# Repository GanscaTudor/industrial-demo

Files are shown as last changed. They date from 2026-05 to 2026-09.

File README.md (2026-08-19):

# Industrial Demo — 10BASE-T1L Control Network

Industrial control network demo using Analog Devices 10BASE-T1L Single Pair Ethernet. A Raspberry Pi running Kuiper Linux 2 acts as the central controller, communicating with multiple ADI evaluation boards over T1L to drive servomotors, control an LED, read temperatures, and drive a DC fan — all managed from a single Python GUI.

## Mechanical Design

<table>
  <tr>
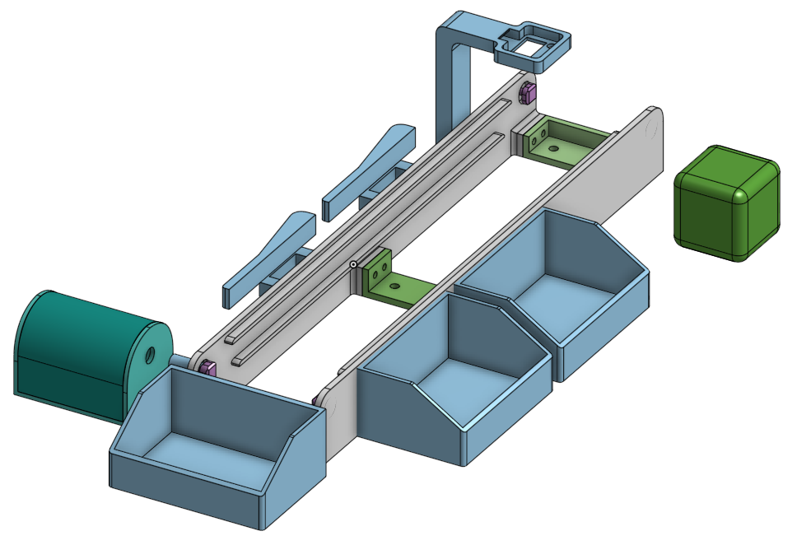
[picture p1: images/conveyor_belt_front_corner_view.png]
Conveyor Belt — Front Corner View
    <td></td>
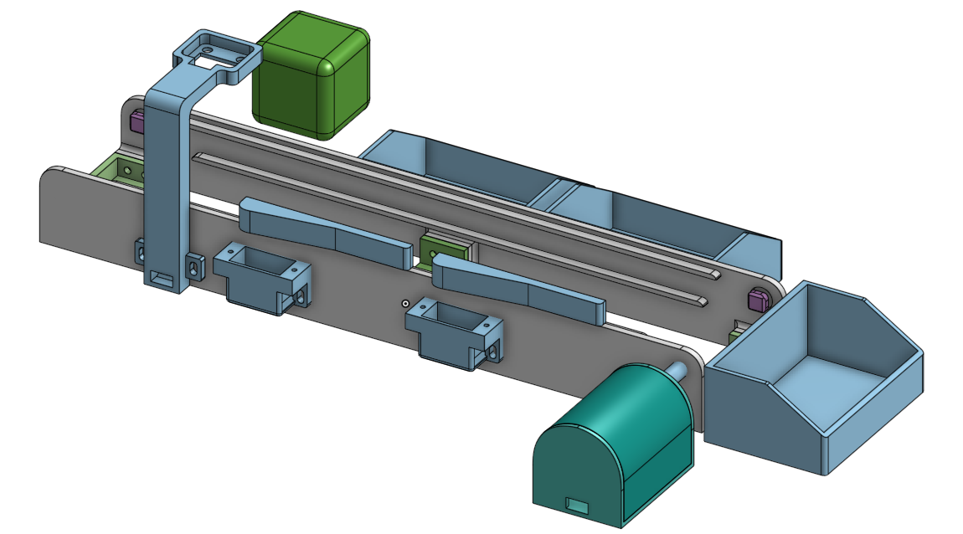
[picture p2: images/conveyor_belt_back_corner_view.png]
Conveyor Belt — Back Corner View
    <td></td>
  </tr>
</table>

### Bill of Materials (BOM)

| Part | Description | Part No. | Qty | Vendor | Filament (g) |
| --- | --- | --- | ----- | --- | --- |
| Roller bearing | Deep groove ball bearing, 3×10×4 mm, double-shielded | SKF 623-2Z | 4 | [TME](https://www.tme.eu/en/details/skf623-2z/roller-bearings/skf/623-2z-skf/) | — |
| DC gearmotor | 195:1 metal gearmotor, 20D×44L mm, 6V | Pololu 3707 | 1 | [TME](https://www.tme.eu/en/details/pololu-3707/dc-motors/pololu/195-1-metal-gearmotor-20dx44l-mm-6v-cb/) | — |
| Color sensor | Analog color sensor (colorimeter) | DFRobot SEN0212 | 1 | [TME](https://www.tme.eu/ro/details/df-sen0212/senzori-de-mediu/dfrobot/sen0212/) | — |
| Accelerometer eval board | Low noise, low drift 3-axis accelerometer, PMOD board | EVAL-ADXL355-PMDZ | 1 | [Analog Devices](https://www.analog.com/en/resources/evaluation-hardware-and-software/evaluation-boards-kits/eval-adxl355-pmdz.html) | — |
| Threaded insert | Brass threaded insert for plastic parts (used with the 14 M3 screws below) | Tappex KVT-M3 (KVT-117M3) | 14 | [TME](https://www.tme.eu/ro/details/kvt-117m3/inserturi-filetate/tappex/117m3/) | — |
| M3 screw | For the threaded inserts above | Generic M3 | 10 | — | — |
| M3 screw | For servo / color sensor / ADXL355 holder mounting (paired with nut below) | Generic M3 | 14 | — | — |
| M3 nut | Paired with the 14 holder-mounting screws above | Generic M3 | 14 | — | — |
| 3D-printed parts | Chassis, holders, connectors — see[`CAD/parts`](CAD/parts/) and [`CAD/printable`](CAD/printable/) | Custom | 1 set | In-house (3D print) | ~700 (PLA or PETG) |

### CAD Files

CAD files are in [`CAD/`](CAD/):

- `CAD/assembly/` — full assembly (STEP)
- `CAD/parts/` — individual custom parts (STEP), named by part number
- `CAD/printable/` — 3D-printable parts (3MF)

### Build Steps

1. 3D-print all parts.
2. Heat-set the threaded inserts into the `side` part using a soldering iron.
3. Assemble the side panels using the connectors and screws into the inserts.
4. Drill holes in the side panel at the locations where the servo holder and color sensor holder will be mounted.
5. Mount the hardware into its holders (servo into its holder, DC motor into its case, color sensor into its housing, etc.).
6. Mount the housings with the hardware onto the side panel at the drilled holes, using M3 screws and nuts.
7. Insert the connectors into the bearing bores and each bearing into its position. Note that one bearing uses the elongated connector, which mates with the longer connector going into the motor's connecting shaft. In this step also fit the bearings into the side panel, with the belt driveshaft connecting through the bearing.
8. Attach the motor housing to the side panel using the heat-set inserts and M3 screws, leaving a small amount of play so the shafts self-align horizontally.
9. Check that the overall structure is rigid and that all screws are fully tightened.
10. Finally, position the conveyor belt and assemble it using the 3D-printed pins together with the belt.
11. *(Optional)* The `side` part and the `box` parts are designed with an internal empty cavity for embedding magnets — two 10×2 mm magnets in `side` and two 10×1 mm magnets in `box`. Mind the polarity so the two parts attract each other once assembled. To embed them, use a 3D-print slicer that supports pausing the print at a given layer/height: pause at the last layer of the cavity, place the magnet, then resume the print.

## Hardware

| Board | Description | IP Address |
| --- | --- | --- |
| Raspberry Pi 4 + [AD-RPI-T1LPSE-SL](https://www.analog.com/en/resources/evaluation-hardware-and-software/evaluation-boards-kits/ad-rpi-t1lpse-sl.html) | Main controller — runs the GUI, acts as TCP client and SPoE PSE | 192.168.98.1  |
| [AD-APARD32690-SL](https://www.analog.com/en/resources/evaluation-hardware-and-software/evaluation-boards-kits/ad-apard32690-sl.html) #1 + [AD-APARDPFWD-SL](https://www.analog.com/en/resources/evaluation-hardware-and-software/evaluation-boards-kits/ad-apardpfw-sl.html)  | APARD #1 — MAX32690 MCU with ADIN2111 (dual-port T1L MAC-PHY) | 192.168.98.50 |
| [AD-APARD32690-SL](https://www.analog.com/en/resources/evaluation-hardware-and-software/evaluation-boards-kits/ad-apard32690-sl.html) #2 + [AD-APARDSPOE-SL](https://www.analog.com/en/resources/evaluation-hardware-and-software/evaluation-boards-kits/ad-apardspoe-sl.html) | APARD #2 — MAX32690 MCU with ADIN1110 (single-port T1L MAC-PHY) | 192.168.98.60 |
| Raspberry Pi 4 + [EVAL-CN0575-RPIZ](https://analogdevicesinc.github.io/documentation/solutions/reference-designs/eval-cn0575-rpiz/index.html) | CN0575 — ADT75 temperature sensor and ADXL355 over T1L | 192.168.10.2  |
| [AD-T1LUSB-EBZ](https://analogdevicesinc.github.io/documentation/solutions/reference-designs/ad-apard32690-sl/ad-t1lusb-ebz/index.html) | USB-to-T1L adapter — plugged into a USB port on the main RPi | — |
| [EVAL-AD-SWIOT1L-SL](https://www.analog.com/en/resources/evaluation-hardware-and-software/evaluation-boards-kits/ad-swiot1l-sl.html) | SWIOT1L — MAX14906 digital output + AD74413R analog I/O (independently powered) | 192.168.97.40 |

### Additional Components

- 2x servomotors connected to APARD #1 (driven over TMR1 and TMR2 pins)
- 1x LED + 330 ohm resistor on APARD #2 (wired to P2.7 / GPIO_2 on header P7)
- DC fan connected to SWIOT1L MAX14906 channel 0 (digital output for PWM)
- EVAL-ADXL355-PMDZ connected on SPI1 of the Raspberry Pi 4 + CN0575
- Single Pair Ethernet cables (T1L) between Main RPi, APARD #1, APARD #2, and CN0575
- SWIOT1L connects to the main RPi via the AD-T1LUSB-EBZ USB-to-T1L adapter (not directly through the T1LPSE)
- USB cables for flashing APARD boards via DAPLINK
- MaxDAP Pico programmer for OpenOCD flashing

## Network Topology

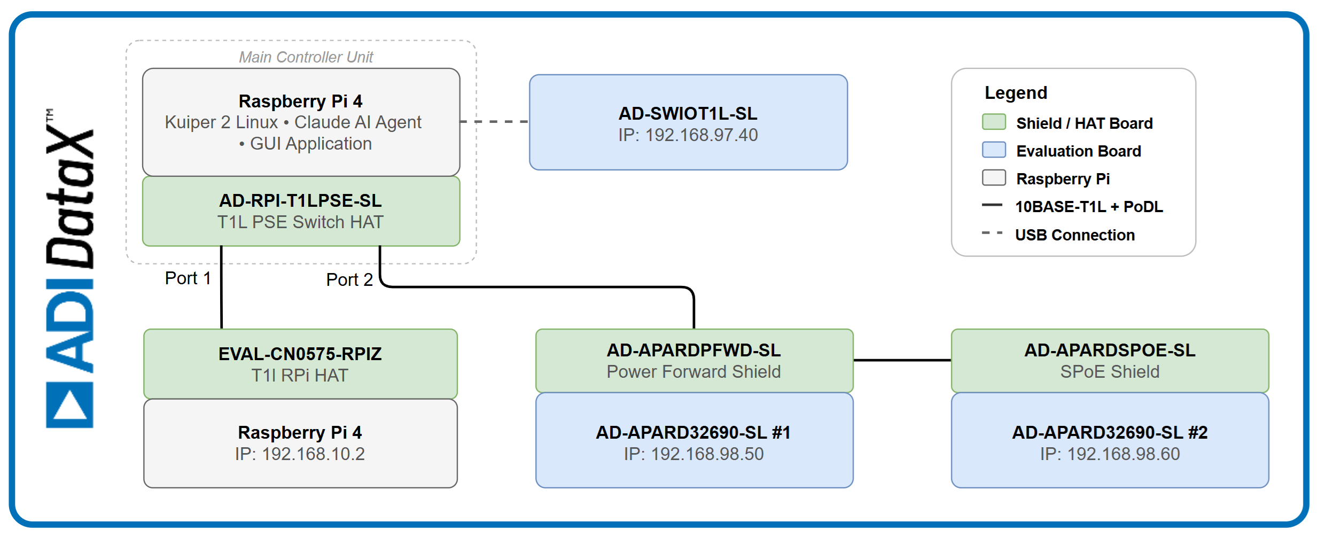
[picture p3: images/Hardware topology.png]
Hardware Topology


## Software and Firmware

### Operating Systems

| Target | OS / Framework |
| --- | --- |
| Main RPi (T1LPSE) | [ADI Kuiper Linux 2.0](https://wiki.analog.com/resources/tools-software/linux-software/kuiper-linux) |
| CN0575 RPi | [ADI Kuiper Linux 2.0](https://wiki.analog.com/resources/tools-software/linux-software/kuiper-linux) |
| APARD #1 and #2 | [no-OS](https://github.com/analogdevicesinc/no-OS) bare-metal C (MAX32690) |
| SWIOT1L | [no-OS](https://github.com/analogdevicesinc/no-OS) bare-metal C (MAX32650) |

### Python Dependencies (Main RPi)

```
matplotlib
pyadi-iio
```

## Setup Guide

### Phase 1 — System Verification

#### Build a Custom Kuiper Image for the AD-RPI-T1LPSE-SL

Clone the ADI Kuiper repository on a build machine (not the target RPi) using the branch specific to the AD-RPI-T1LPSE-SL:

```bash
git clone --depth 1 --branch kuiper-AD-RPI-T1LPSE-SL https://github.com/analogdevicesinc/kuiper
cd kuiper
sudo ./build-docker.sh
```

For full build options see the [Kuiper Quick Start](https://wiki.analog.com/resources/tools-software/linux-software/kuiper-linux). Once the image is built, write it to a micro-SD card and boot the Raspberry Pi.

#### Configure the SD Card for ADI-RPI-T1LPSE-SL

The Linux kernel requires a device tree overlay to identify the AD-RPI-T1LPSE-SL hardware. The overlay is included in Kuiper and only needs to be enabled. Add the following line to `/boot/config.txt`:

```
dtoverlay=rpi-t1lpse-class12
```

Place this line under the `[Pi4]` section for Raspberry Pi 4, or under `[Pi5]` for Raspberry Pi 5.

```

After reboot, confirm the overlay is loaded:

```bash
dtoverlay -l | grep t1lpse
```

#### Configure the SD Card for CN0575

To use the EVAL-CN0575-RPIZ with the Raspberry Pi, the micro-SD card should be preloaded with [Kuiper Linux](https://wiki.analog.com/resources/tools-software/linux-software/kuiper-linux).

Complete instructions, including where to download the SD card image, how to write it to the micro-SD card, and how to configure the system are provided at the [Kuiper page](https://wiki.analog.com/resources/tools-software/linux-software/kuiper-linux).

#### Enable the CN0575 + ADXL355 Overlay

The `rpi-cn0575-adxl355-overlay` is a custom overlay (not part of the standard Kuiper or Raspberry Pi overlay set). It must be compiled from source and installed manually before it can be enabled.

Compile the overlay on the CN0575 Raspberry Pi:

```bash
dtc -@ -I dts -O dtb -o rpi-cn0575-adxl355-overlay.dtbo RPI_CN0575/rpi-cn0575-adxl355-overlay.dts
sudo cp rpi-cn0575-adxl355-overlay.dtbo /boot/overlays/
```

Add the following line to `/boot/config.txt`:

```
dtoverlay=rpi-cn0575-adxl355-overlay
```

Reboot and confirm the overlay is loaded:

```bash
dtoverlay -l | grep cn0575-adxl
```

### Phase 2 — Install Prerequisites

Install build tools, libraries, and SDKs on the main RPi.

#### Build Tools and ARM Toolchain

```bash
sudo apt update
sudo apt install -y git make gcc-arm-none-eabi libnewlib-arm-none-eabi
```

Verify the installation:

```bash
arm-none-eabi-gcc --version
make --version | head -1
git --version
```

#### MaximSDK (headers and libraries only)

```bash
git clone https://github.com/analogdevicesinc/msdk.git ~/MaximSDK
```

Create a GNUTools symlink so the no-OS build system finds the system compiler:

```bash
mkdir -p ~/MaximSDK/Tools/GNUTools/10.3/bin
ln -s /usr/bin/arm-none-eabi-* ~/MaximSDK/Tools/GNUTools/10.3/bin/
```

Add the environment variable to `~/.bashrc`:

```bash
echo 'export MAXIM_LIBRARIES=~/MaximSDK/Libraries' >> ~/.bashrc
source ~/.bashrc
```

#### no-OS

Clone the fork with the APARD LED control examples:

```bash
git clone --recursive https://github.com/GanscaTudor/no-OS.git --branch industrial-demo ~/no-OS
```

This branch contains two projects used in the demo:

- `projects/apardpfwd` — apard_servo_control example for APARD #1 (ADIN2111 / PFWD shield) — the firmware must expose `SERVO1_ON`, `SERVO1_OFF`, `SERVO2_ON`, `SERVO2_OFF`, `SERVO_STATUS` over TCP port 10000
- `projects/apardspoe` — `apardspoe_led_control_example` for APARD #2 (ADIN1110 / SPOE shield)

Append the required peripheral driver sources to each project's build file:

```bash
cat >> ~/no-OS/projects/apardpfwd/src.mk << 'EOF'

SRCS += $(MAXIM_LIBRARIES)/PeriphDrivers/Source/SYS/mxc_delay.c \
        $(MAXIM_LIBRARIES)/PeriphDrivers/Source/SYS/mxc_lock.c

INCS += $(MAXIM_LIBRARIES)/PeriphDrivers/Include/MAX32690/mxc_delay.h \
        $(MAXIM_LIBRARIES)/PeriphDrivers/Include/MAX32690/mxc_lock.h
EOF

cat >> ~/no-OS/projects/apardspoe/src.mk << 'EOF'

SRCS += $(MAXIM_LIBRARIES)/PeriphDrivers/Source/SYS/mxc_delay.c \
        $(MAXIM_LIBRARIES)/PeriphDrivers/Source/SYS/mxc_lock.c

INCS += $(MAXIM_LIBRARIES)/PeriphDrivers/Include/MAX32690/mxc_delay.h \
        $(MAXIM_LIBRARIES)/PeriphDrivers/Include/MAX32690/mxc_lock.h
EOF
```

#### libiio (v0 branch)

```bash
sudo apt-get install -y libxml2 libxml2-dev bison flex libcdk5-dev cmake \
    libaio-dev libusb-1.0-0-dev libserialport-dev libavahi-client-dev

git clone https://github.com/analogdevicesinc/libiio.git --branch libiio-v0 ~/libiio
cd ~/libiio && mkdir build && cd build
cmake .. -DPYTHON_BINDINGS=ON
make -j && sudo make install
sudo ldconfig
```

#### pyadi-iio

```bash
sudo apt-get install -y python3 libatlas-base-dev
git clone https://github.com/analogdevicesinc/pyadi-iio ~/pyadi-iio
cd ~/pyadi-iio
sudo python3 -m pip install -r requirements_prod_test.txt
sudo pip install .
```

#### OpenOCD (ADI fork)

```bash
sudo apt-get install -y libtool pkg-config libusb-1.0-0-dev libhidapi-dev libgpiod-dev

mkdir -p ~/work && cd ~/work
git clone https://github.com/analogdevicesinc/openocd -b "0.12.0-1.1.2" --depth 1 --recurse-submodules
cd openocd
./bootstrap
./configure --enable-cmsis-dap --enable-linuxgpiod --disable-werror
make -j && sudo make install
```

#### Network Manager

```bash
sudo apt-get install -y network-manager
```

### Phase 3 — Build Firmware

Build both APARD projects. Each project's Makefile defaults to `apard_communication_example`, so override with the `EXAMPLE=` flag to build the desired example.

#### APARD #1 — apard_servo_control (ADIN2111, IP 192.168.98.50)

```bash
cd ~/no-OS/projects/apardpfwd
make clean && make RELEASE=y -j EXAMPLE=<apard_servo_control>
cp build/apardpfwd.elf /home/analog/apard1.elf
```

#### APARD #2 — `apardspoe_led_control_example` (ADIN1110, IP 192.168.98.60)

```bash
cd ~/no-OS/projects/apardspoe
make clean && make RELEASE=y -j EXAMPLE=apardspoe_led_control_example
cp build/apardspoe.elf /home/analog/apard2.elf
```

#### SWIOT1L Firmware

Download the pre-built SWIOT1L static IP firmware from the official release:

```bash
wget -O /home/analog/swiot1l_static_ip.hex \
    https://github.com/analogdevicesinc/no-OS/releases/download/swiot1l-v1.1.0/swiot1l_maxim_swiot1l_static_ip.hex
```

### Phase 4 — Flash Firmware

All boards are flashed using OpenOCD with a MaxDAP Pico (CMSIS-DAP) programmer.

#### Flash APARD #1

Connect the MaxDAP Pico to APARD #1, then run:

```bash
openocd -f interface/cmsis-dap.cfg -f target/max32690.cfg \
    -c "program /home/analog/apard1.elf verify reset exit"
```

#### Flash APARD #2

Move the MaxDAP Pico to APARD #2, then run:

```bash
openocd -f interface/cmsis-dap.cfg -f target/max32690.cfg \
    -c "program /home/analog/apard2.elf verify reset exit"
```

#### Flash SWIOT1L

Connect the DAPLink to the SWIOT1L board, then run:

```bash
openocd -f interface/cmsis-dap.cfg -f target/max32690.cfg \
    -c "program /home/analog/swiot1l_static_ip.hex verify reset exit"
```

### Phase 5 — Network Configuration

The demo uses multiple network interfaces and subnets. Configure each on the main RPi.

#### T1LPSE Interface (APARD subnet — 192.168.98.x)

The T1LPSE hat creates an Ethernet interface for the 10BASE-T1L network. Assign a static IP for the APARD boards:

```bash
sudo nmcli connection add type ethernet con-name t1l-apard \
    ifname <t1l-interface> \
    ipv4.addresses 192.168.98.1/24 \
    ipv4.method manual
sudo nmcli connection up t1l-apard
```

#### CN0575 Interface (CN0575 subnet — 192.168.10.x)

The CN0575 RPi is on a separate subnet, reached through a different T1L port on the T1LPSE:

```bash
sudo nmcli connection add type ethernet con-name t1l-cn0575 \
    ifname <cn0575-t1l-interface> \
    ipv4.addresses 192.168.10.1/24 \
    ipv4.method manual
sudo nmcli connection up t1l-cn0575
```

#### USB-T1L Interface (SWIOT1L subnet)

The AD-T1LUSB-EBZ adapter creates a separate Ethernet interface for the SWIOT1L:

```bash
sudo nmcli connection add type ethernet con-name t1l-swiot \
    ifname <usb-t1l-interface> \
    ipv4.addresses 192.168.97.1/24 \
    ipv4.method manual
sudo nmcli connection up t1l-swiot
```

#### Verify Connectivity

Once all boards are powered and the network is configured, verify connectivity:

```bash
ping -c 3 192.168.98.50   # APARD #1
ping -c 3 192.168.98.60   # APARD #2
ping -c 3 192.168.10.2    # CN0575
ping -c 3 192.168.97.40   # SWIOT1L
```

### Phase 6 — Start the Demo

#### 1. Start the CN0575 and ADXL355 server

On the CN0575 Raspberry Pi:

Clone the demo repository:

```bash
ssh analog@192.168.10.2
git clone https://github.com/ganscatudor/industrial-demo
```

Start the servers:

```bash
ssh analog@192.168.10.2
python3 /home/analog/industrial-demo/RPI_CN0575/adxl355_server.py --rate 1000 --chunk 256 --port 50055
python3 /home/analog/industrial-demo/RPI_CN0575/cn0575_state_machine.py
```

This starts a TCP server that reads the ADXL355 accelerations and temperature readings from adt75.

#### 2. Run the control panel

On the main RPi:

Clone the demo repository

```bash
git clone https://github.com/ganscatudor/industrial-demo
```

```bash
pip3 install matplotlib pyadi-iio
python3 RPI_T1LPSE/demo.py --adxl-host 192.168.10.2
```

The GUI provides:

- **APARD #1** — Independent ON/OFF control for two servomotors (Servo 1, Servo 2) plus servo status readback over TCP
- **APARD #2** — LED on/off control and LED status readback over TCP
- **CN0575** — Live ADXL355 vibration monitoring and ADT75 temperature graph with auto-refresh
- **SWIOT1L** — Fan PWM duty cycle control with live RPM graph (via pyadi-iio)

## Communication Protocols

### APARD Boards (TCP port 10000)

Text-based, newline-terminated. One TCP connection per command.

| Command | Response | Description |
| --- | --- | --- |
| `LED_ON\n` | `OK\n` | Set LED GPIO high |
| `LED_OFF\n` | `OK\n` | Set LED GPIO low |
| `LED_STATUS\n` | `LED:ON\n` or `LED:OFF\n` | Read current LED state |

### CN0575 (TCP port 10000)

| Command | Response | Description |
| --- | --- | --- |
| `READ_TEMP\n` | `TEMP:24.3\n` | Read ADT75 temperature sensor |

### SWIOT1L (pyadi-iio)

The SWIOT1L is controlled via [pyadi-iio](https://github.com/analogdevicesinc/pyadi-iio) (not TCP). The GUI connects directly using `adi.swiot()` and `adi.max14906()` to set PWM duty cycle on the MAX14906 digital output driving the fan.

## Agentic AI Setup Assistant

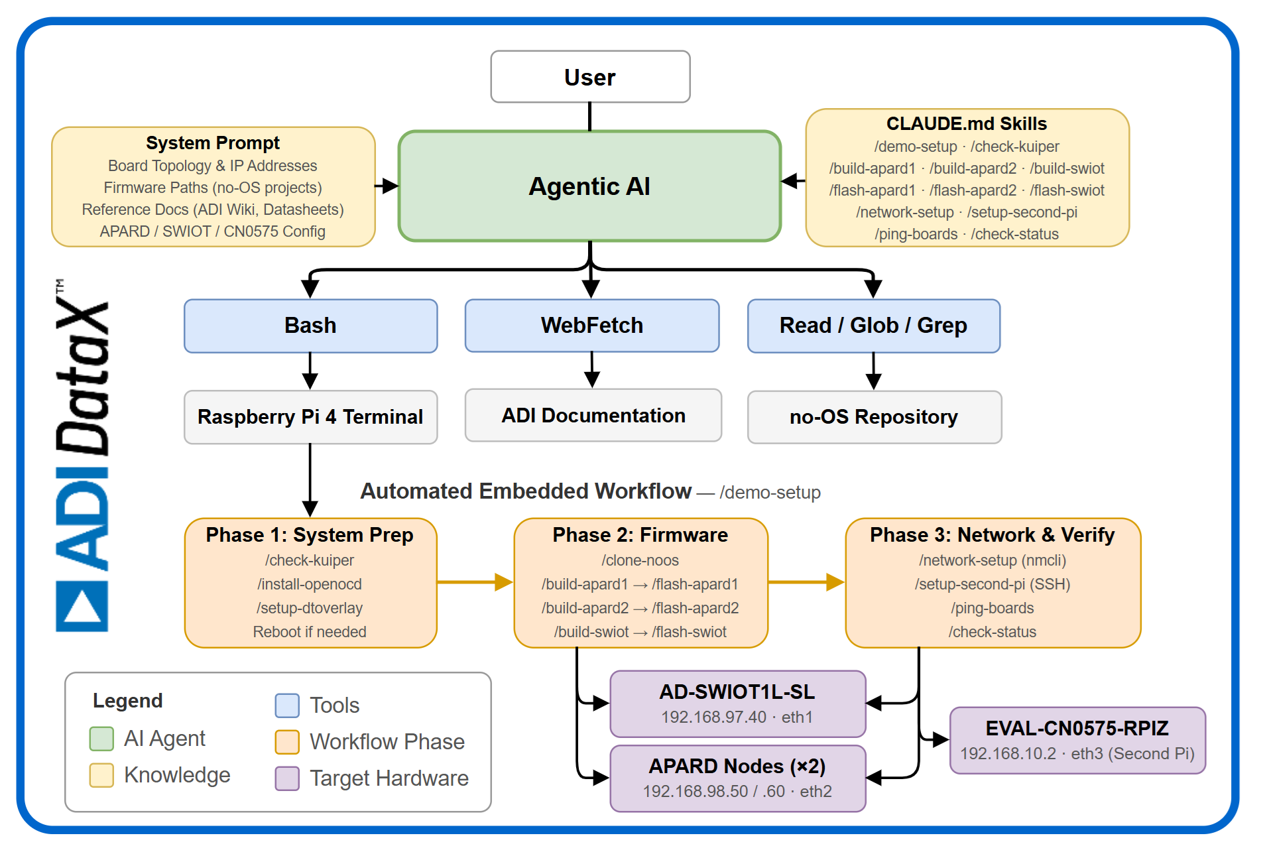
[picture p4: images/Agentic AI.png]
Agentic AI Setup Assistant


This demo includes a Claude Code agent with all setup steps embedded as skills. The agent can walk through the entire setup process interactively — from verifying the Kuiper system and installing prerequisites, to building and flashing firmware, configuring the network, and launching the GUI. It is designed to run directly on the main Raspberry Pi and handles each phase with user confirmation at critical steps (such as moving the programmer between boards).

> **Note:** The agent is still under development and not yet included in this repository.

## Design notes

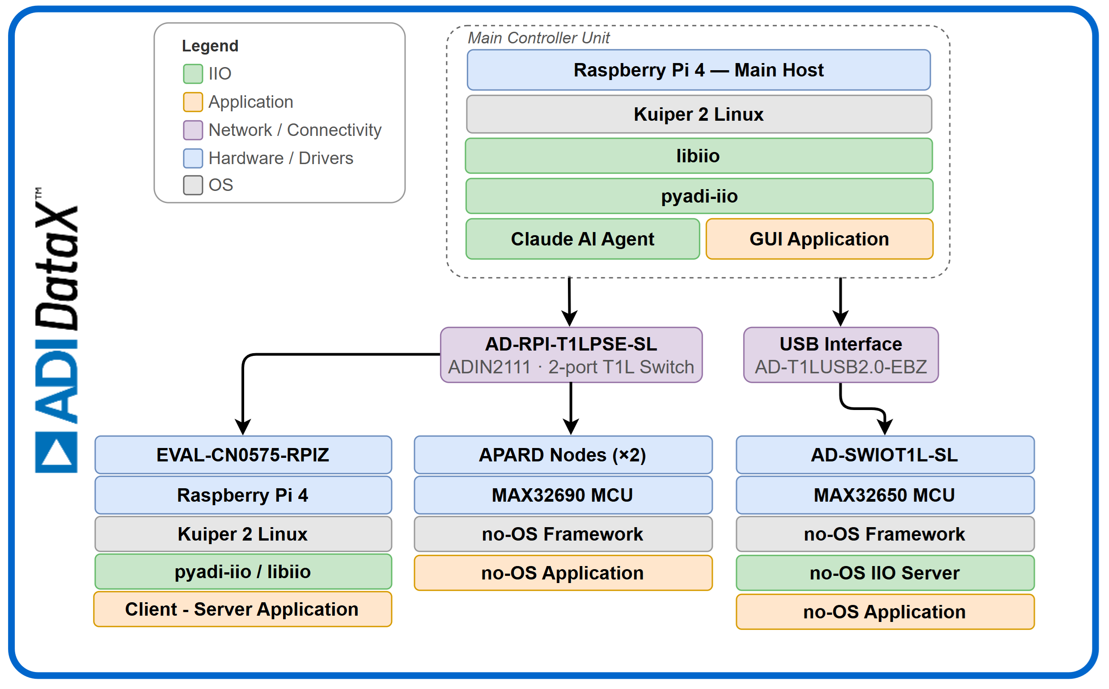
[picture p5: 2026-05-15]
images/Software architecture.png

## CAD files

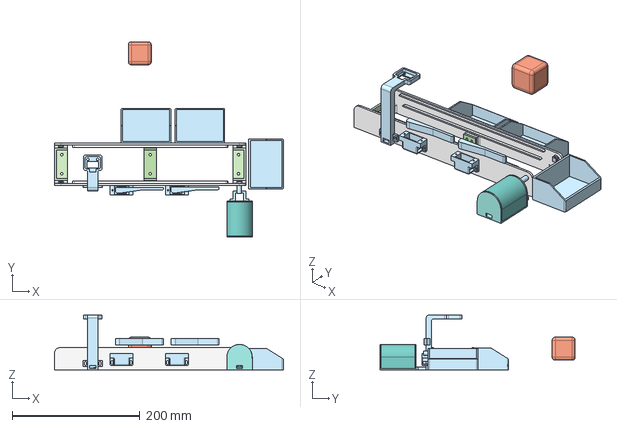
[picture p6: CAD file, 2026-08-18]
CAD/assembly/conveyor_belt_assembly.step
359.0 x 306.2 x 86.1 mm

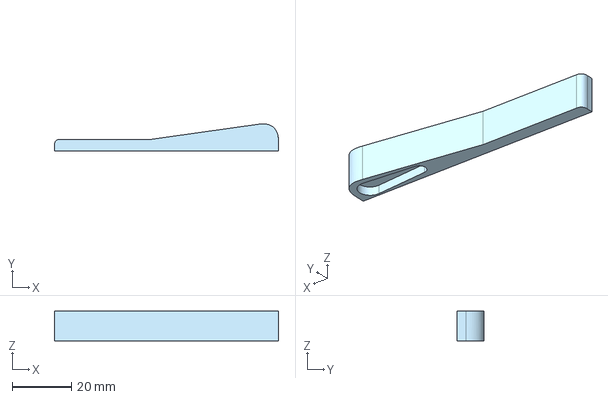
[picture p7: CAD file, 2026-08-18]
CAD/parts/servo_arm.step
75.4 x 9.18 x 10.0 mm

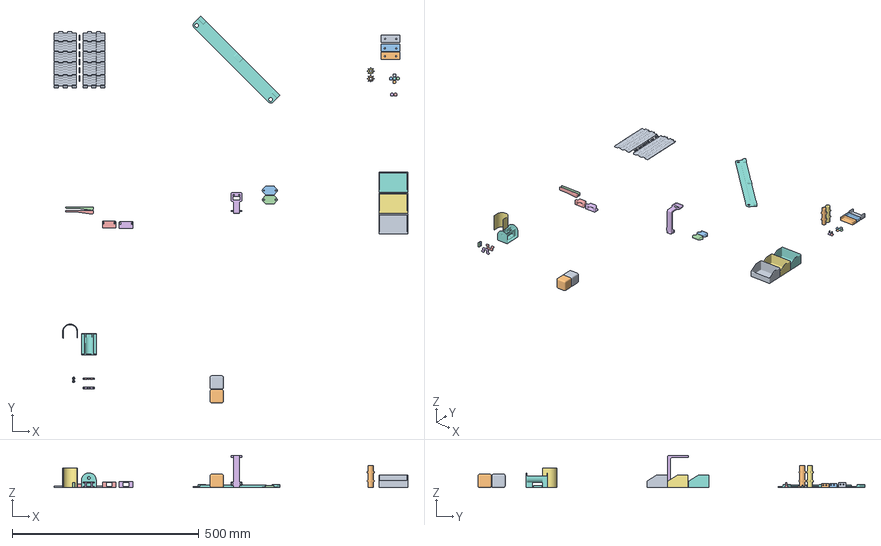
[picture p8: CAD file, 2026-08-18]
CAD/printable/conveyor_belt_3d_print_proj.3mf
947.5 x 1035.9 x 86.0 mm
ChainLinks-EasierToAssemble.stl
Bit Connector.stl x 6
laterala - Part 3.stl
conector_mijloc - Part 1.stl
conectori_laterale - Part 2.stl x 2
brat_servo - Part 1.stl x 2
brat_senzor_culoare - Part 1.stl
cutie - Part 2.stl x 3
driveshaft - Part 1.stl x 2
conector_dc_shaft -ajustat.stl x 2
conector_dc_laterala - Part 1.stl x 2
carcasa_dc - Part 2.stl
carcasa_dc - cu suport_pcb.stl
Assembly x 2
suport_adxl.stl x 2
holder_servo - Part 1.stl x 2
Assembly 1 - bearings_connector (1).step x 5
Assembly 1 - bearing_dc_connector.step x 2

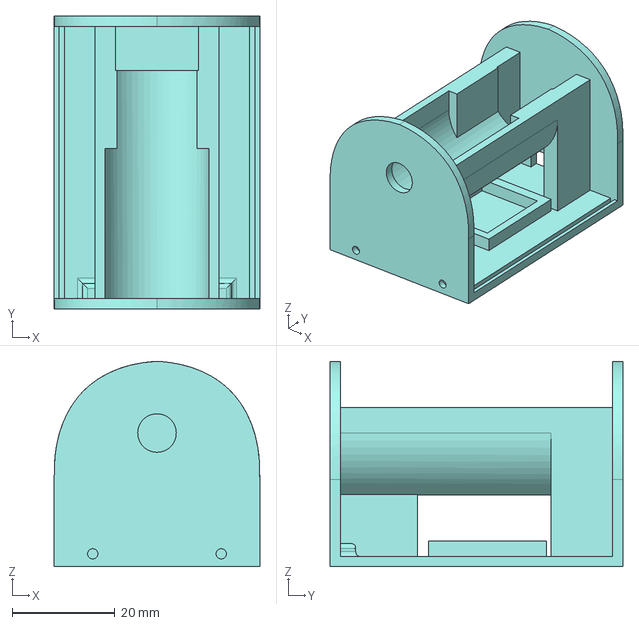
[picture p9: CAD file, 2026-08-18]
CAD/parts/dc_motor_holder.step
40.0 x 57.0 x 39.9 mm

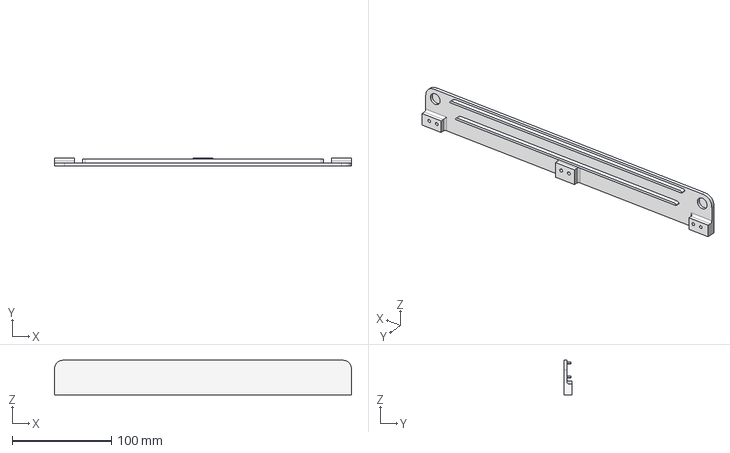
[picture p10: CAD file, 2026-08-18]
CAD/parts/side.step
300.0 x 8.00 x 35.0 mm

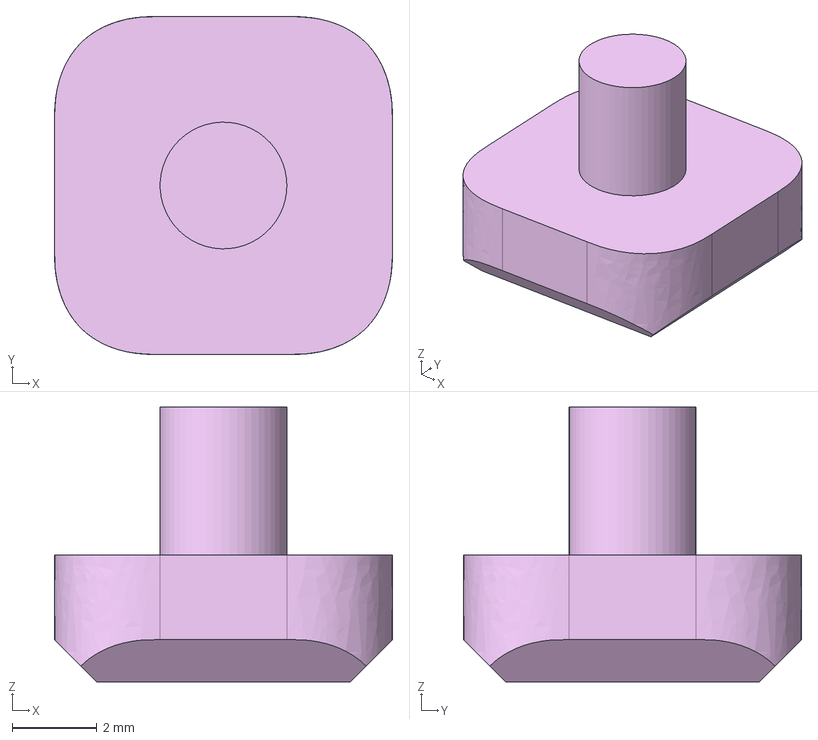
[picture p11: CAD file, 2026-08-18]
CAD/parts/bearings_connector.step
8.00 x 8.00 x 6.50 mm

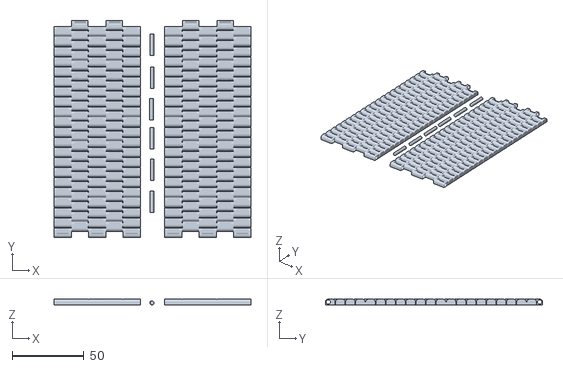
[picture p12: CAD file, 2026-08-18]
CAD/parts/belt.stl
137.0 x 151.0 x 4.00

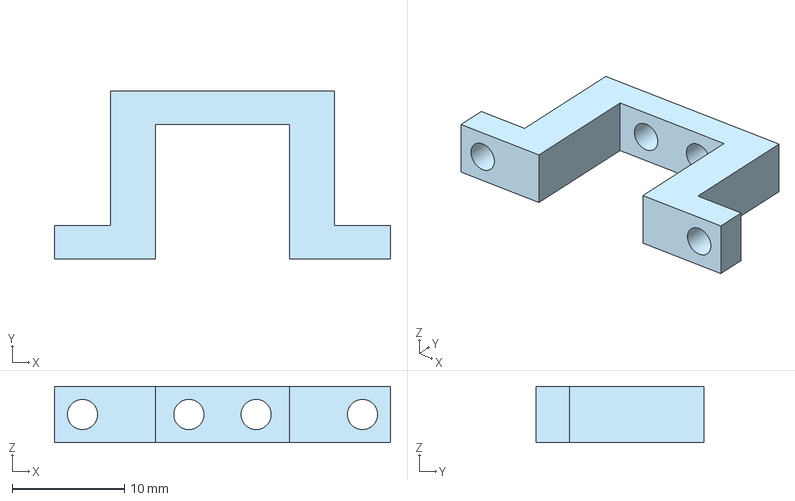
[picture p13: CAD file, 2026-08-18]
CAD/parts/dc_side_connector.step
30.0 x 15.0 x 5.00 mm

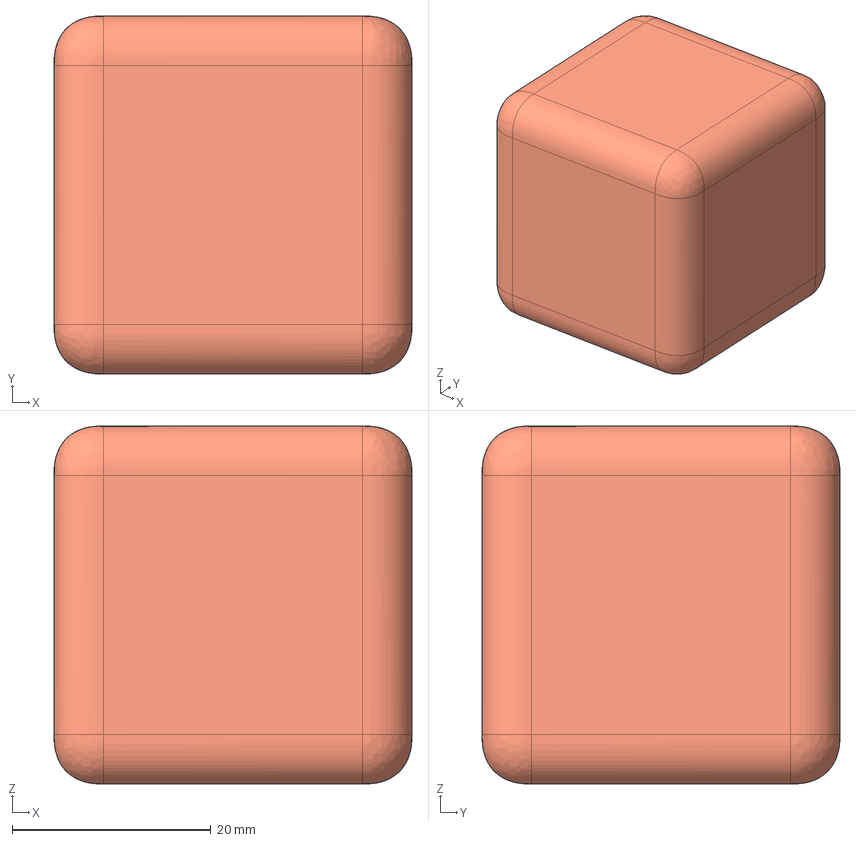
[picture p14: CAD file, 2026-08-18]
CAD/parts/cube.step
36.0 x 36.0 x 36.0 mm

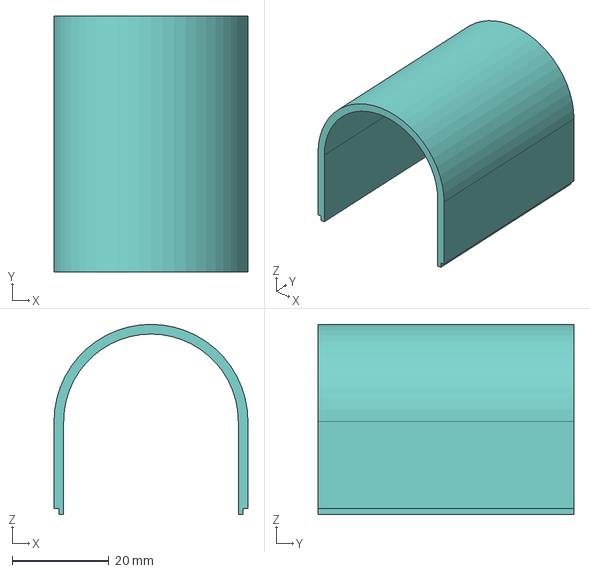
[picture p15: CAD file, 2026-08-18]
CAD/parts/dc_motor_case.step
40.0 x 52.8 x 39.3 mm

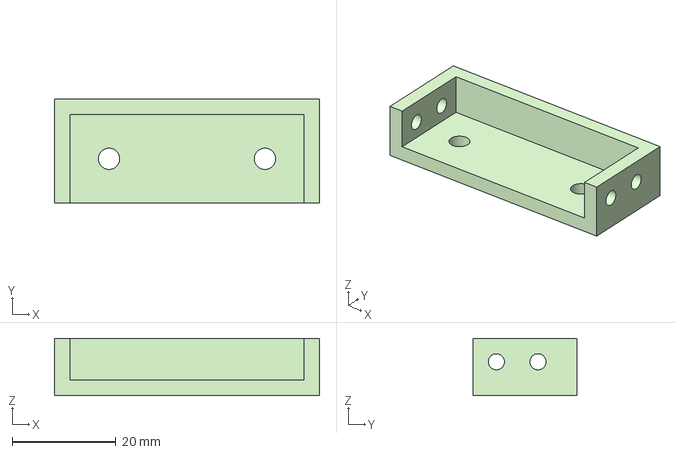
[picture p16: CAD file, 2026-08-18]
CAD/parts/sides_connectors.step
51.0 x 20.0 x 11.0 mm

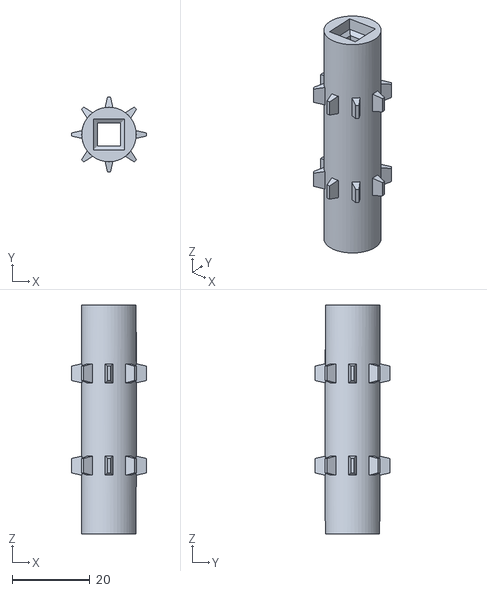
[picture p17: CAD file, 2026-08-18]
CAD/parts/driveshaft.stl
19.2 x 19.2 x 58.8

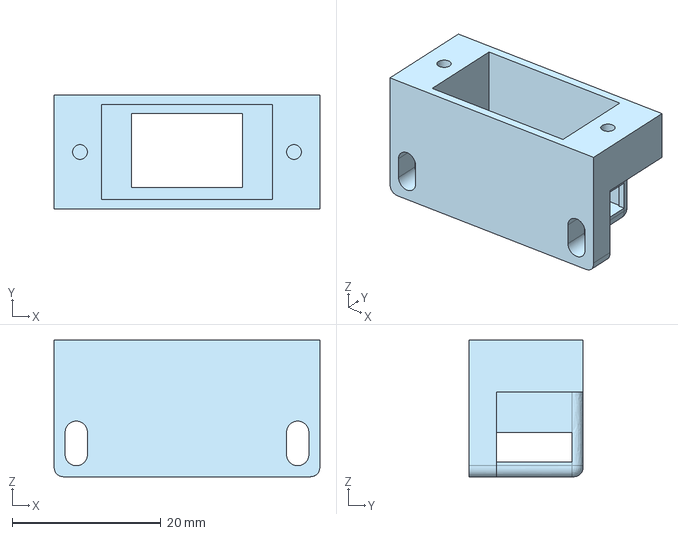
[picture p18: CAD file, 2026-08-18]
CAD/parts/servo_holder.step
35.8 x 15.4 x 18.4 mm

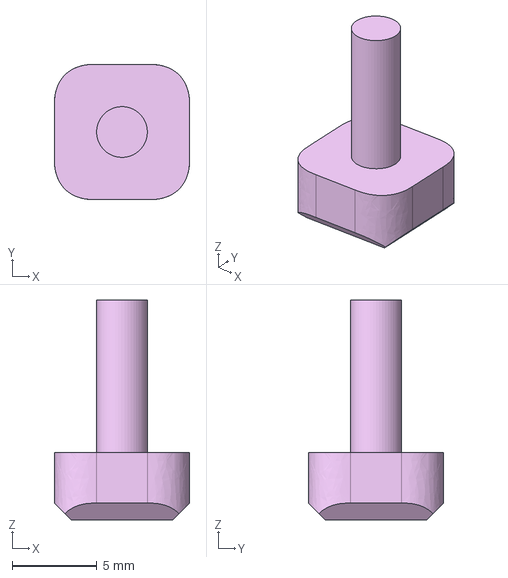
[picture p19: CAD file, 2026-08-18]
CAD/parts/bearing_dc_connector.step
8.00 x 8.00 x 13.0 mm

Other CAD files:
CAD/parts/sides_middle_connector.step
CAD/parts/color_sensor_holder.step
CAD/parts/dc_shaft_connector.step
CAD/parts/box.step

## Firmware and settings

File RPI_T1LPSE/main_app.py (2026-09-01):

#!/usr/bin/env python3
"""
ADI DataX™ - AI-driven 10BASE-T1L Deployment
(color sensor variant: COLOR_READ polled at 4 Hz over IP)

Combined application integrating:
- APARD board control (Servo, TCS34725 color sensor)
- CN0575 temperature monitoring
- SWIOT1L fan PWM control
- ADXL355 predictive maintenance monitor

Styled to the design system in CLAUDE.md (see design_system.py): approved
palette, light/dark themes, card-based panels, 8px-radius primary buttons and
the 4-48px spacing scale.

Requirements:
    pip3 install matplotlib pyadi-iio numpy

Usage:
    python3 main_app.py                     # real hardware, light theme
    python3 main_app.py --theme dark        # real hardware, dark theme
    python3 main_app.py --demo              # synthetic data for every panel
    python3 main_app.py --adxl-host IP      # ADXL355 server address
"""

import argparse
import json
import math
import os
import socket
import struct
import subprocess
import threading
import time
from datetime import datetime
from collections import deque
import numpy as np
import tkinter as tk
import tkinter.font as tkfont
from tkinter import ttk, scrolledtext, simpledialog

from design_system import (
    PRIMARY, NEUTRAL, SUCCESS, WARNING, ERROR, INFO,
    THEMES, XS, SM, MD, LG, XL, XXL,
    LEVEL_COLOR, AXIS_COLORS, COLOR_AXIS_COLORS, status_text_color,
    pick_font, Button, Card, FanIndicator, ThemeMixin,
)

try:
    from matplotlib.figure import Figure
    from matplotlib.backends.backend_tkagg import FigureCanvasTkAgg
    HAS_MATPLOTLIB = True
except ImportError:
    HAS_MATPLOTLIB = False
    print("Warning: matplotlib not found. Graphs will be disabled.")
    print("Install with: pip3 install matplotlib")

try:
    import adi
    HAS_ADI = True
except ImportError:
    HAS_ADI = False
    print("Warning: pyadi-iio not found. SWIOT1L panel will be disabled.")
    print("Install with: pip3 install pyadi-iio")

# ---------------------------------------------------------------------------
# CLI arguments
# ---------------------------------------------------------------------------
parser = argparse.ArgumentParser()
parser.add_argument("--demo", action="store_true",
                    help="Synthetic data for every panel (no hardware needed)")
parser.add_argument("--theme", choices=["light", "dark"], default="light")
parser.add_argument("--adxl-host", type=str, default="localhost", help="ADXL355 server IP")
parser.add_argument("--adxl-port", type=int, default=50055, help="ADXL355 server port")
parser.add_argument("--adxl-rate", type=int, default=1000, help="ADXL355 sample rate")
parser.add_argument("--adxl-buf", type=int, default=2048, help="FFT window size")
parser.add_argument("--adxl-chunk", type=int, default=256, help="Samples per acquisition")
args = parser.parse_args()

# ---------------------------------------------------------------------------
# Network configuration
# ---------------------------------------------------------------------------
APARD1_IP = "192.168.98.50"
APARD2_IP = "192.168.98.60"
CN0575_IP = "192.168.10.2"
SWIOT_IP = "192.168.97.40"
TCP_PORT = 10000
TIMEOUT = 2.0
AUTO_REFRESH_MS = 5000
COLOR_AUTO_REFRESH_MS = 250  # 4 reads/sec over IP for the color sensor panel
GRAPH_MAX_POINTS = 60
DC_RPM = 4500
PWM_PERIOD = 0.01

# ADXL355 settings
ADXL_FS = args.adxl_rate
ADXL_FFT_WIN = args.adxl_buf
ADXL_CHUNK = args.adxl_chunk
ADXL_FREQ_MAX = min(500, ADXL_FS / 2)
M_S2_TO_G = 1.0 / 9.80665

# Remote server launch (the "Start Servers" button on the ADXL355 panel).
# Both scripts are accept-loop servers that never return, so they must be
# started detached and concurrently -- running them in sequence would block on
# the first and never bind the ADXL port.
REMOTE_HOST = f"analog@{CN0575_IP}"
REMOTE_LOG_DIR = "/tmp"
SSH_CONNECT_TIMEOUT = 8          # seconds; the ssh call itself returns at once
REMOTE_SERVERS = (
    # (label, directory, script, args, log basename)
    ("CN0575 command server", "industrial-demo/RPI_CN0575",
     "cn0575_state_machine.py", "", "cn0575_state_machine"),
    ("ADXL355 data server", "vibration-demo",
     "adxl355_server.py",
     f"--rate {ADXL_FS} --chunk {ADXL_CHUNK} --port {args.adxl_port}",
     "adxl355_server"),
)

# Predictive maintenance thresholds
THRESH_WARN = 2000.0
THRESH_ALARM = 6000.0
CREST_WARN = 6.0
KURT_WARN = 6.0

AXIS_NAMES = ["X", "Y", "Z"]

# TCS34725 color sensor settings
COLOR_AXIS_NAMES = ["R", "G", "B"]

# AXIS_COLORS, COLOR_AXIS_COLORS and LEVEL_COLOR now come from design_system so
# the plot series and health indicators use the CLAUDE.md palette.

# Color-cube detection -> automatic servo triggering.
# Runs continuously in the background, independent of the "Live" display checkbox.
COLOR_CUBE_THRESHOLD = 500

# Header logo target height in px (see ControlPanel._load_logo).
LOGO_HEIGHT = 30

RED_SERVO_DELAY_S = 0.0
RED_SERVO_ON_DURATION_S = 4.0

GREEN_SERVO_DELAY_S = 3
GREEN_SERVO_ON_DURATION_S = 3.5


# ---------------------------------------------------------------------------
# Utility: TCP command sender
# ---------------------------------------------------------------------------
def send_command(ip, cmd, timeout=TIMEOUT):
    """Open connection, send one command, read response, close."""
    try:
        with socket.socket(socket.AF_INET, socket.SOCK_STREAM) as s:
            s.settimeout(timeout)
            s.connect((ip, TCP_PORT))
            s.sendall((cmd + "\n").encode("ascii"))
            data = s.recv(1024)
            if not data:
                return None
            return data.decode("ascii").strip()
    except (socket.error, OSError):
        return None


# ---------------------------------------------------------------------------
# Demo mode: synthetic stand-ins for the hardware
#
# Every board read funnels through send_command(), so one replacement covers the
# servo, colour and temperature panels. Response strings match the real device
# protocol exactly, so the parsers and the cube-detection logic run unmodified.
# ---------------------------------------------------------------------------
_demo_t0 = None


def _demo_elapsed():
    global _demo_t0
    if _demo_t0 is None:
        _demo_t0 = time.monotonic()
    return time.monotonic() - _demo_t0


def demo_send_command(ip, cmd, timeout=TIMEOUT):
    """Protocol-accurate synthetic replies. Mirrors send_command's contract."""
    elapsed = _demo_elapsed()

    if cmd == "SERVO_STATUS":
        return "SERVO1:OFF,SERVO2:OFF"
    if cmd in ("SERVO1_ON", "SERVO1_OFF", "SERVO2_ON", "SERVO2_OFF"):
        return "OK"

    if cmd == "COLOR_READ":
        # 30 s loop: neutral -> red cube -> neutral -> green cube -> neutral.
        # Cube phases exceed COLOR_CUBE_THRESHOLD so _check_cube_trigger fires
        # the servo sequences; neutral phases stay well below it.
        t = elapsed % 30.0
        if 8.0 <= t < 12.0:
            r, g, b = 1800, 310, 290          # RED  -> SERVO1 sequence
        elif 20.0 <= t < 24.0:
            r, g, b = 280, 1600, 310          # GREEN -> SERVO2 sequence
        else:
            r = int(120 + 20 * math.sin(elapsed * 0.30))
            g = int(120 + 15 * math.sin(elapsed * 0.20 + 1.0))
            b = int(120 + 18 * math.sin(elapsed * 0.25 + 2.0))
        return f"R:{r},G:{g},B:{b}"

    if cmd == "READ_TEMP":
        return f"TEMP:{22.0 + 3.0 * math.sin(elapsed * 0.05):.1f}"

    return None


class _DemoChannel:
    """Stands in for max14906.channel['voltageN'] — accepts .raw writes."""
    raw = 0


class _DemoADIDevice:
    """Accepts the attribute writes the SWIOT1L panel performs on real devices."""

    def __init__(self, *_args, **_kwargs):
        self.channel = {f"voltage{i}": _DemoChannel() for i in range(4)}
        self.mode = "config"

    def __setattr__(self, name, value):
        object.__setattr__(self, name, value)

    def __getattr__(self, name):
        return 0


if args.demo:
    send_command = demo_send_command


# ---------------------------------------------------------------------------
# ADXL355 Data Sources
# ---------------------------------------------------------------------------
class DemoSource:
    """Generates synthetic vibration: 50 Hz fundamental + harmonics + noise."""

    def __init__(self):
        self._t = 0.0
        self._fault = False
        self._fault_timer = 0

    def read_chunk(self, n):
        t = np.linspace(self._t, self._t + n / ADXL_FS, n, endpoint=False)
        self._t += n / ADXL_FS
        data = []
        for axis_i in range(3):
            freq = [50, 100, 150][axis_i]
            amp = [0.05, 0.03, 0.02][axis_i]
            sig = amp * np.sin(2 * np.pi * freq * t)
            sig += 0.01 * np.random.randn(n)
            if axis_i == 0:
                self._fault_timer += n
                if self._fault_timer > ADXL_FS * 8:
                    self._fault_timer = 0
                    self._fault = True
                if self._fault:
                    idx = np.random.randint(0, n)
                    sig[idx] += 0.8 * np.random.choice([-1, 1])
                    self._fault = False
            data.append(sig * 9.80665)
        return data


class TCPSource:
    """TCP client for adxl355_server.py."""

    def __init__(self, host, port):
        self._sock = socket.socket(socket.AF_INET, socket.SOCK_STREAM)
        self._sock.connect((host, port))
        self._sock.settimeout(10.0)
        cfg = json.loads(self._recv_msg())
        self.fs = cfg["fs"]
        self.chunk = cfg["chunk"]

    def _recvall(self, n):
        buf = bytearray()
        while len(buf) < n:
            pkt = self._sock.recv(n - len(buf))
            if not pkt:
                raise ConnectionError("Server closed connection")
            buf.extend(pkt)
        return bytes(buf)

    def _recv_msg(self):
        length = struct.unpack(">I", self._recvall(4))[0]
        return self._recvall(length)

    def read_chunk(self, _n):
        msg = self._recv_msg()
        arr = np.frombuffer(msg, dtype=np.float32).reshape(3, -1)
        return [arr[i] for i in range(3)]


class ADXL355Acquisition:
    """Threaded acquisition for ADXL355 data."""

    def __init__(self, source):
        self._source = source
        self._buf = [np.zeros(ADXL_FFT_WIN) for _ in range(3)]
        self._lock = threading.Lock()
        self._running = False
        self._thread = None

    def start(self):
        if self._running:
            return
        self._running = True
        self._thread = threading.Thread(target=self._loop, daemon=True)
        self._thread.start()

    def stop(self):
        self._running = False

    def snapshot(self):
        with self._lock:
            return [b.copy() for b in self._buf]

    def _loop(self):
        while self._running:
            try:
                raw = self._source.read_chunk(ADXL_CHUNK)
            except Exception:
                time.sleep(0.1)
                continue
            with self._lock:
                for i in range(3):
                    chunk = np.asarray(raw[i], dtype=np.float64) * M_S2_TO_G
                    self._buf[i] = np.roll(self._buf[i], -len(chunk))
                    self._buf[i][-len(chunk):] = chunk


def compute_metrics(samples):
    """Compute RMS, peak, crest factor, kurtosis."""
    ac = samples - samples.mean()
    rms = float(np.sqrt(np.mean(ac ** 2)))
    peak = float(np.abs(ac).max())
    cf = peak / rms if rms > 1e-9 else 0.0
    std = ac.std()
    kurt = float(np.mean((ac / std) ** 4)) if std > 1e-9 else 3.0
    return rms, peak, cf, kurt


def health_level(rms, cf, kurt):
    """Determine health status from metrics."""
    if rms < THRESH_WARN:
        return "OK"
    if rms >= THRESH_ALARM or cf >= CREST_WARN * 1.5 or kurt >= KURT_WARN * 2:
        return "ALARM"
    if cf >= CREST_WARN or kurt >= KURT_WARN:
        return "WARNING"
    return "OK"


# ---------------------------------------------------------------------------
# UI Panels
# ---------------------------------------------------------------------------
class CardPanel(tk.Frame):
    """Base for every hardware panel: a themed Card with a title and a
    status row.

    Panels are plain tk.Frame (not ttk.LabelFrame) because ttk widgets ignore
    bg=/fg= and a LabelFrame's built-in title is only reachable through the
    global TLabelframe.Label style, which cannot be re-themed per panel at
    runtime. The Card supplies the border/shadow/padding from CLAUDE.md and the
    title becomes a real tk.Label we can recolour directly.
    """

    def __init__(self, parent, tm, title, subtitle=""):
        super().__init__(parent)
        self.tm = tm
        self._card = Card(self, tm, pad=MD)
        self._card.outer().pack(fill=tk.BOTH, expand=True)
        self.body = self._card.body

        self._title_lbl = tk.Label(self.body, text=title, anchor="w",
                                   font=tm.font_h2)
        self._title_lbl.pack(fill="x")
        self._subtitle_lbl = None
        if subtitle:
            self._subtitle_lbl = tk.Label(self.body, text=subtitle, anchor="w",
                                          font=tm.font_small)
            self._subtitle_lbl.pack(fill="x", pady=(0, SM))
        else:
            self._title_lbl.pack_configure(pady=(0, SM))

        # Widgets whose colours track the theme, registered by subclasses.
        self._plain_labels = []      # follow text/card
        self._muted_labels = []      # follow text2/card
        self._frames = []            # follow card bg

    # -- theme plumbing ----------------------------------------------------
    def register_theme(self):
        """Call at the end of __init__, once the UI exists."""
        self.tm.on_theme(self.apply_theme)

    def track(self, *widgets, muted=False):
        """Mark labels/frames to be recoloured on every theme switch.

        Always returns the first widget so it can be chained:
            self.track(tk.Label(...)).pack(...)
        """
        for w in widgets:
            if isinstance(w, tk.Label):
                (self._muted_labels if muted else self._plain_labels).append(w)
            else:
                self._frames.append(w)
        return widgets[0]

    def apply_theme(self):
        t = self.tm.theme
        self.configure(bg=t["bg"])
        self._title_lbl.configure(bg=t["card"], fg=t["text"])
        if self._subtitle_lbl is not None:
            self._subtitle_lbl.configure(bg=t["card"], fg=t["text_dis"])
        for w in self._frames:
            try:
                w.configure(bg=t["card"])
            except tk.TclError:
                pass
        for w in self._plain_labels:
            w.configure(bg=t["card"], fg=t["text"])
        for w in self._muted_labels:
            w.configure(bg=t["card"], fg=t["text2"])
        # The status label's fg encodes state, but the accessible shade for that
        # state differs per theme, so it is re-resolved here rather than fixed.
        if getattr(self, "status_label", None) is not None:
            self.status_label.configure(
                bg=t["card"],
                fg=status_text_color(self.tm.theme_name, self._status_key))
        self.style_plot()

    def style_plot(self):
        """Overridden by panels that embed a matplotlib figure."""

    def theme_axes(self, fig, ax, canvas):
        """Apply the CLAUDE.md palette to an embedded matplotlib axes."""
        t = self.tm.theme
        fig.patch.set_facecolor(t["card"])
        ax.set_facecolor(t["card"])
        ax.tick_params(colors=t["text2"], labelsize=7)
        for sp in ax.spines.values():
            sp.set_color(t["border"])
        ax.grid(True, color=t["border"], lw=0.5, alpha=0.6)
        ax.xaxis.label.set_color(t["text2"])
        ax.yaxis.label.set_color(t["text2"])
        ax.title.set_color(t["text"])
        leg = ax.get_legend()
        if leg is not None:
            for txt in leg.get_texts():
                txt.set_color(t["text2"])
        canvas.get_tk_widget().configure(bg=t["card"], highlightthickness=0)
        canvas.draw_idle()

    def status_row(self, label_text="Status:", value="Unknown",
                   button_text=None, button_cmd=None):
        """Build the shared 'Status: <value>  [Action]' row.

        The value is a tk.Label (not ttk) because its foreground carries state
        and a named ttk style would override per-widget colours.
        """
        row = tk.Frame(self.body)
        row.pack(fill="x", pady=(0, SM))
        self._frames.append(row)
        cap = tk.Label(row, text=label_text, font=self.tm.font_small)
        cap.pack(side="left")
        self._muted_labels.append(cap)
        self.status_label = tk.Label(row, text=value, font=self.tm.font_bold)
        self.status_label.pack(side="left", padx=(XS, 0))
        self._status_key = "idle"
        btn = None
        if button_text:
            btn = Button(row, self.tm, button_text, button_cmd,
                         variant="primary", height=28)
            btn.pack(side="right")
        return row, btn

    def set_status(self, text, key):
        """Set the status text and its semantic colour together.

        CLAUDE.md: colour is never the only indicator, so the wording changes
        alongside the colour.
        """
        self._status_key = key
        self.status_label.config(text=text,
                                 fg=status_text_color(self.tm.theme_name, key),
                                 bg=self.tm.theme["card"])


def rgb_counts_to_hex(r, g, b):
    """Normalize raw 16-bit ADC counts to a displayable sRGB swatch color."""
    peak = max(r, g, b, 1)
    scale = 255.0 / peak
    rr = min(int(r * scale), 255)
    gg = min(int(g * scale), 255)
    bb = min(int(b * scale), 255)
    return f"#{rr:02x}{gg:02x}{bb:02x}"
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

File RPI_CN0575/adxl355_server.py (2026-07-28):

#!/usr/bin/env python3
"""
adxl355_server.py — runs on the Raspberry Pi with the ADXL355 connected.

Streams accelerometer data (m/s²) over TCP to the monitoring GUI.

Usage:
    python adxl355_server.py [--rate 1000] [--chunk 256] [--port 50055] [--demo]
"""
import argparse
import json
import socket
import struct
import numpy as np

parser = argparse.ArgumentParser()
parser.add_argument("--rate",  type=int, default=1000,  help="Sample rate (Hz)")
parser.add_argument("--chunk", type=int, default=256,   help="Samples per frame")
parser.add_argument("--port",  type=int, default=50055, help="TCP port to listen on")
parser.add_argument("--demo",  action="store_true",     help="Synthetic data (no hardware)")
args = parser.parse_args()

FS    = args.rate
CHUNK = args.chunk
PORT  = args.port

# ---------------------------------------------------------------------------
# Demo source (no hardware)
# ---------------------------------------------------------------------------
class DemoSource:
    def __init__(self):
        self._t = 0.0
        self._fault_timer = 0

    def read_chunk(self, n):
        t = np.linspace(self._t, self._t + n / FS, n, endpoint=False)
        self._t += n / FS
        data = []
        for i in range(3):
            freq = [50, 100, 150][i]
            amp  = [0.05, 0.03, 0.02][i]
            sig  = amp * np.sin(2 * np.pi * freq * t) + 0.01 * np.random.randn(n)
            if i == 0:
                self._fault_timer += n
                if self._fault_timer > FS * 8:
                    self._fault_timer = 0
                    idx = np.random.randint(0, n)
                    sig[idx] += 0.8 * np.random.choice([-1, 1])
            data.append(sig * 9.80665)   # m/s²
        return data

# ---------------------------------------------------------------------------
# Hardware source
# ---------------------------------------------------------------------------
def make_source():
    if args.demo:
        print("DEMO mode — no hardware required")
        return DemoSource()

    try:
        import adi
        print("Connecting to ADXL355...")
        dev = adi.adxl355()
        try:
            dev.sample_rate = FS
            print(f"Sample rate set: {int(dev.sample_rate)} Hz")
        except AttributeError:
            print(f"Sample rate fixed at {FS} Hz")
        dev.rx_buffer_size = CHUNK

        class _Dev:
            def read_chunk(self, _n):
                return dev.rx()   # returns list of 3 arrays in m/s²

        return _Dev()
    except Exception as exc:
        print(f"Could not connect to ADXL355: {exc}")
        print("Tip: run with --demo to test without hardware")
        raise SystemExit(1)

# ---------------------------------------------------------------------------
# TCP server helpers
# ---------------------------------------------------------------------------
def _send_msg(conn: socket.socket, payload: bytes) -> None:
    """Length-prefix a message and send it."""
    conn.sendall(struct.pack('>I', len(payload)) + payload)

# ---------------------------------------------------------------------------
# Main loop
# ---------------------------------------------------------------------------
def main():
    source = make_source()

    srv = socket.socket(socket.AF_INET, socket.SOCK_STREAM)
    srv.setsockopt(socket.SOL_SOCKET, socket.SO_REUSEADDR, 1)
    srv.bind(('0.0.0.0', PORT))
    srv.listen(1)
    print(f"Listening on 0.0.0.0:{PORT}  |  FS={FS} Hz  |  chunk={CHUNK}")

    while True:
        conn, addr = srv.accept()
        print(f"Client connected: {addr}")
        try:
            # Handshake: send server config so the client can validate settings
            cfg = json.dumps({"fs": FS, "chunk": CHUNK}).encode()
            _send_msg(conn, cfg)

            while True:
                raw = source.read_chunk(CHUNK)         # list of 3 arrays, m/s²
                arr = np.array(raw, dtype=np.float32)  # shape (3, N)
                _send_msg(conn, arr.tobytes())

        except (BrokenPipeError, ConnectionResetError, OSError) as exc:
            print(f"Client disconnected: {exc}")
        finally:
            conn.close()


if __name__ == "__main__":
    main()

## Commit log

2026-05-07 Add links for boards
2026-05-25 Add new main RPi app for servo control and modify readme
2026-07-28 Add new main for color detection togheter with servo actuation
2026-08-18 Add mechanical design: CAD files, BOM, and build steps
    [bearing_dc_connector.step, bearings_connector.step, belt.stl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]
2026-08-19 Add optional magnet-embedding step to build instructions
2026-09-01 redesign industrial demo application
    [main_app.py]
2026-09-01 add sorting button
2026-09-01 retune adxl thresholds, fix server launch, prompt for ssh password
    [main_app.py]
2026-09-01 fix servo timing under load, add cube color calibration, replaced fan graph with an animation
    [main_app.py]
